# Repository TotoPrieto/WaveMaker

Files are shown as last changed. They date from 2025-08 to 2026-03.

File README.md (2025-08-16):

# 🌊 WaveMaker

**WaveMaker** is a wave generator developed at the **LEICI Laboratory** of the **Facultad de Ingenieria - UNLP**, designed to simulate wave motion inside a small water tank. It was created to test various wave amplitudes and speeds, with the final goal of supporting the study of waves energy harvesting systems placed inside the tank (a oscillating water column – not part of this project).

## 🛠️ Technical Description

The system uses a vertical linear actuator driven by a stepper motor, moving a wedge inside the tank to generate waves. One limit switch defines the zero position (home), while the second acts as a safety limit in case of unexpected movement or step miscounts.

### 🧩 Components

- Arduino UNO  
- CNC Shield V3 for Arduino  
- A4988 Stepper Motor Driver  
- NEMA17 Stepper Motor, 1.8º
- 24V 3A Power Supply  
- 2 Limit Switches  
- Power, Reset and speed mode Buttons
- Potentiometer

### 💻 Software

The firmware was developed using **PlatformIO**, programmed in **C++** with the **Arduino** library.

Included features:

- Homing routine using limit switches  
- Stepper control for vertical movement along Z-axis  
- Error handling and movement boundaries
- Selectable speed modes via button
- Amplitude control via analog potentiometer

## 🎚️ Speed Modes

The system includes **three selectable speed modes** using the dedicated speed selector button. Each mode modifies the way the stepper motor drives the vertical actuator, demonstrating different wave behaviors in the tank.

### Mode 1 – Variable Amplitude with Acceleration
- **Description:** The motor moves with acceleration and deceleration, and the amplitude of movement is adjustable using the analog potentiometer.
- **Implementation:** Uses `stepper.run()` from the `<AccelStepper.h>` library.
- **Purpose:** Demonstrates how changing the stroke amplitude directly affects the wave size, allowing for controlled testing of wave heights.

### Mode 2 – Constant Speed (No Acceleration)
- **Description:** The motor moves from one limit switch to the opposite one at a fixed speed, without acceleration or deceleration.
- **Implementation:** Uses `stepper.runSpeedToPosition()` from the `<AccelStepper.h>` library.
- **Purpose:** Simulates waves with a more "chaotic" surface, useful for observing the behavior inside the oscillating water column.

### Mode 3 – Accelerated Travel Between Limits
- **Description:** Similar to Mode 2, but movement between limit switches includes acceleration and deceleration.
- **Implementation:** Uses `stepper.run()` from the `<AccelStepper.h>` library.
- **Purpose:** Offers a different approach to crossing the entire stroke, still producing chaotic waves but with smoother motion transitions.

---

**Summary:**  
- Mode 1 focuses on **wave height control** (amplitude adjustment).  
- Modes 2 and 3 focus on **full-stroke chaotic wave generation** but differ in motor acceleration profiles.

## 📐 3D Modeling

The mechanical structure was designed using **AutoCAD** and **Blender**. Below are 3D rendered images of the model:

### Side View  


### Front View  


### Bottom View  


## ⚙️ Installation

1. Clone this repository locally.
2. Open the project using [PlatformIO](https://platformio.org/).
3. Connect the Arduino UNO via USB.
4. Compile and upload the firmware.

## 📁 Project Structure

```
WAVEGENERATOR/
├── .pio/
├── .vscode/
├── include/              # Header files
│   ├── Button.hpp
│   ├── Pins.hpp
│   └── StepperController.hpp
├── lib/ 
├── src/                  # Source code in C++
│   ├── Button.cpp
│   ├── main.cpp
│──  └── StepperController.cpp
├── 3D Models/            # Models Files
```

## ✒️ Authors

Project developed by **Tomas Prieto De Francia**, in colaboration with **Jeronimo Jose More** and **Facundo Mosquera**, and based on previous work by **Facundo Mosquera**, under the LEICI Laboratory at the **Universidad Nacional de La Plata (UNLP)**.

## 🪪 License

This project is licensed under the [MIT License](https://opensource.org/licenses/MIT).  
Feel free to use, modify, and share it for personal, academic, or commercial purposes.

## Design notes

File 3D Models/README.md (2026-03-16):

# 📐 WaveMaker - 3D Model Components

This repository contains 3D model files (`.stl`) designed for the mechanical parts of the **WaveMaker** system. These models were created to support the wave generation mechanism inside a small water tank.

## 🔩 Components Overview

### Slider

- Designed to be driven by a threaded rod via a nut that is inserted into the slider.
- Includes slots to mount linear roller bearings.
- Bearings can be secured using zip ties (cable ties).
- Improves stability and reduces friction during vertical movement.

### Main Body

- One side features a slot for a **ball bearing** to stabilize the threaded rod.
- The opposite side includes a mounting space for a **NEMA17 Stepper Motor (1.8º)**.
- Provides structural support for the entire movement mechanism.

### Wedge (Wave Generator)

- The wedge is a hollow structure used to generate waves inside the tank.
- Comes with a **removable top lid** that can be screwed in place.
- The hollow body allows for optional filling (e.g., sand, water, weights) to **increase mass and wave impact**.

### Control Button Enclosure

An additional 3D printable enclosure for the WaveMaker control buttons.

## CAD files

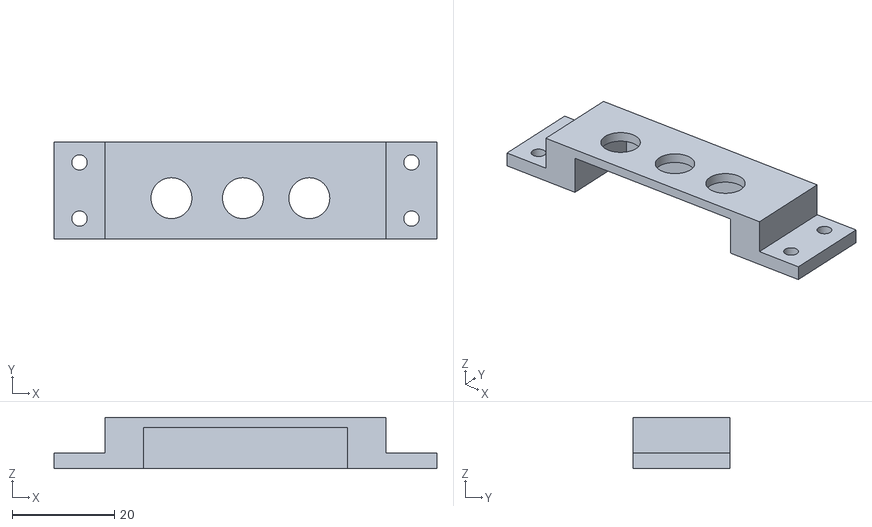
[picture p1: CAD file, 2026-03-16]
3D Models/Botonera.stl
75.0 x 19.0 x 10.0

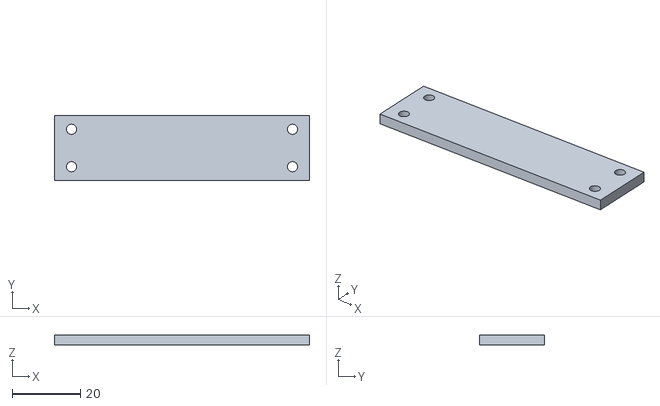
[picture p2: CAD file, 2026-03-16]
3D Models/SueloBotonera.stl
75.0 x 19.0 x 3.00

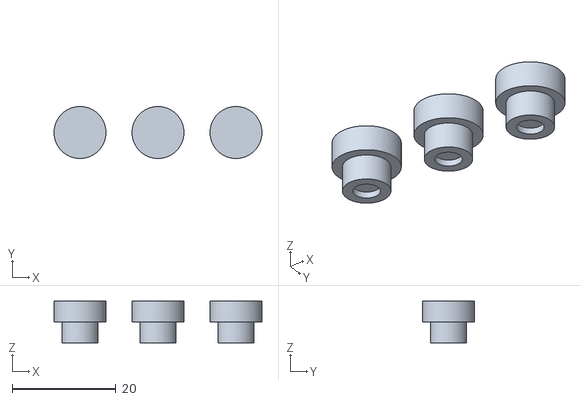
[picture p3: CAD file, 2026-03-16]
3D Models/Botones.stl
40.0 x 10.0 x 8.00

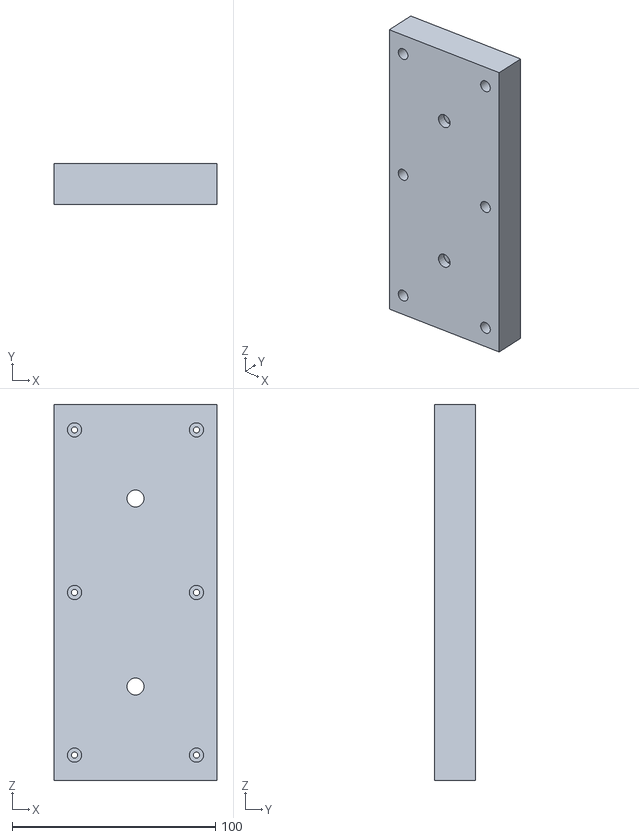
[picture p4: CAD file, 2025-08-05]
3D Models/Wedge-Cap.stl
80.0 x 20.0 x 185.0

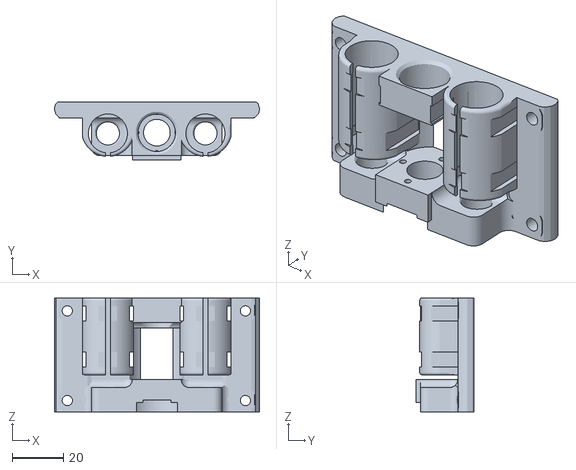
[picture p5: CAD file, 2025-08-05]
3D Models/Slider.stl
80.0 x 22.7 x 44.5

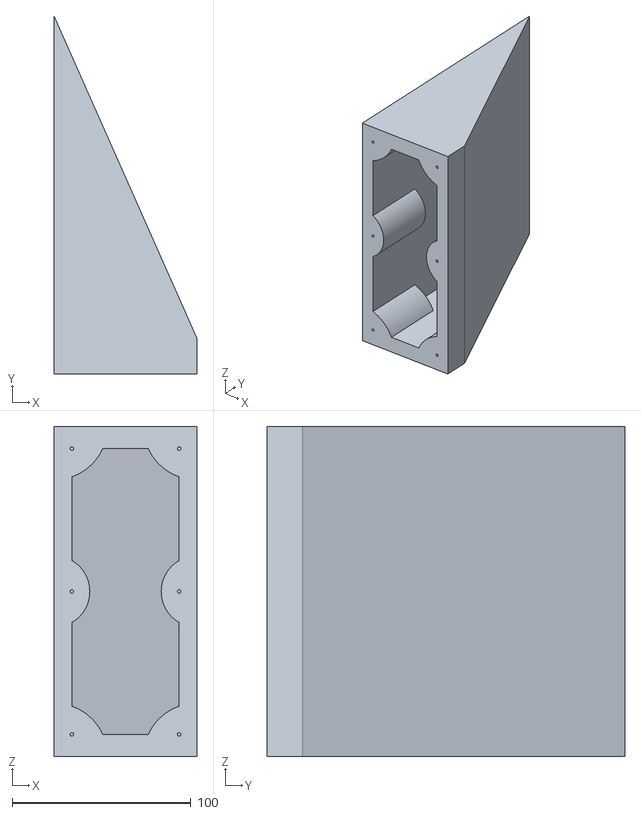
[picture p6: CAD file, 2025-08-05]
3D Models/Wedge.stl
80.0 x 200.4 x 185.0

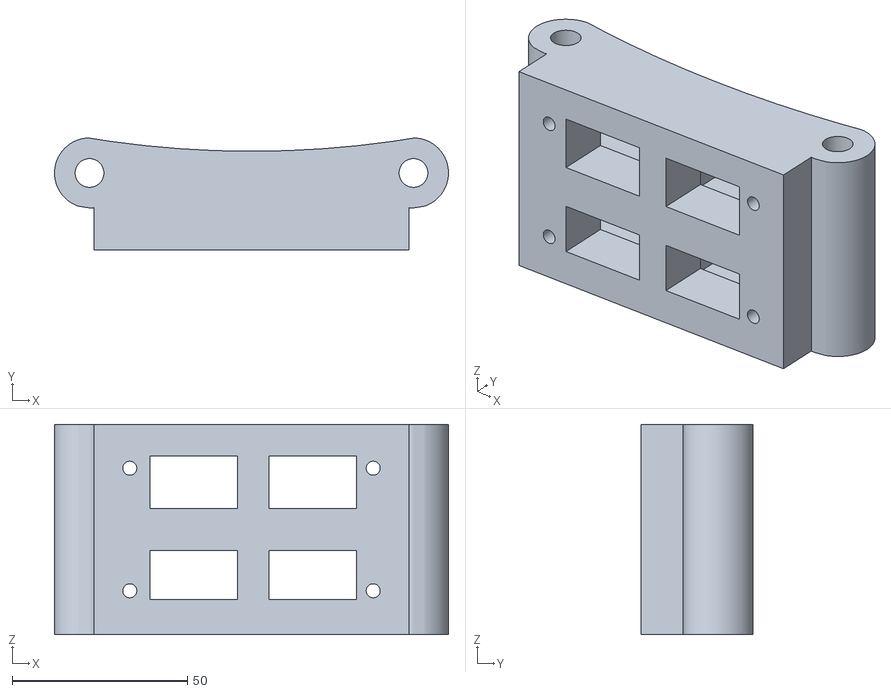
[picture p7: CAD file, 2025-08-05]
3D Models/Arm.stl
112.5 x 32.0 x 60.0

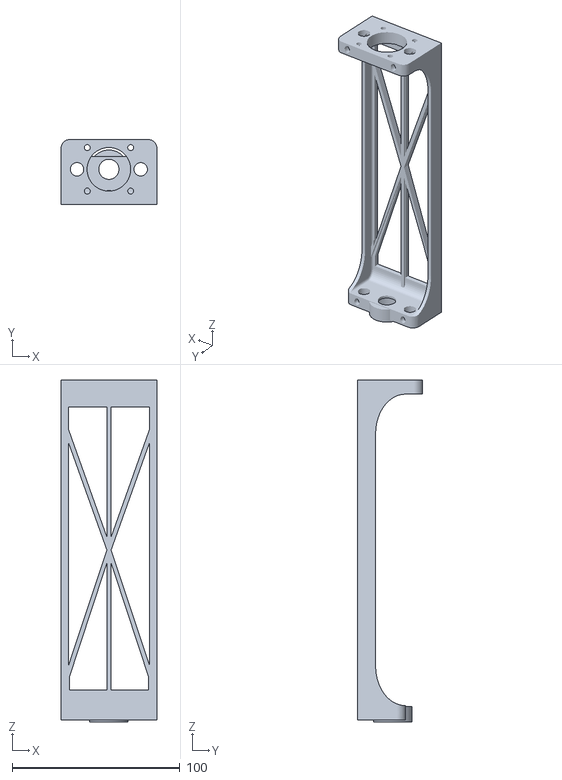
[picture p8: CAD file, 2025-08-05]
3D Models/Body.stl
57.2 x 38.7 x 204.0

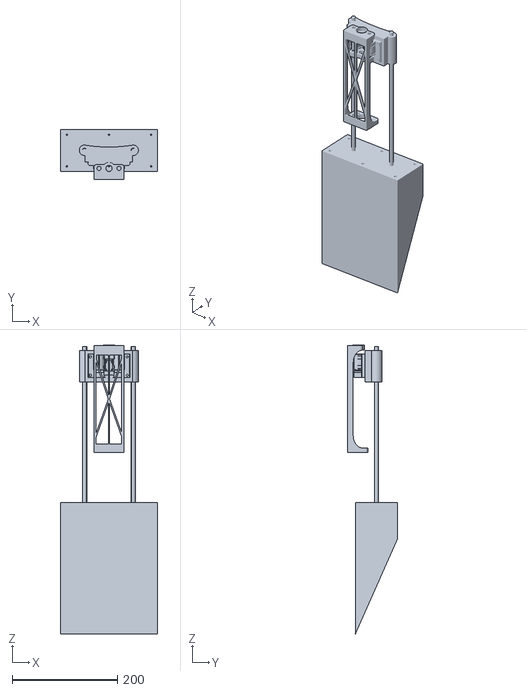
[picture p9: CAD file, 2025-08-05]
3D Models/PiecesTogether.stl
185.0 x 94.8 x 549.3

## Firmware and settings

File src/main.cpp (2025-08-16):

#include <Arduino.h>
#include "StepperController.hpp"
#include "Button.hpp"
#include "Pins.hpp"

//Initial total steps
int steps_Tot = MAX_STEPS;
//State of the system: ON or OFF
volatile bool systemOn = false;
//Define the stepper controller with the pins and total steps
StepperController controller(STEP_PIN, DIR_PIN, ENABLE_PIN);

//My three buttons and both limit switches are active low

//Reset button. Does init action
Button resetButton(RESET_BUTTON_PIN, true, []() {
controller.init(steps_Tot);
});

//Power button to toggle the system state and enable/disable the motor
Button powerButton(POWER_BUTTON_PIN, true, []() {
    systemOn = !systemOn;
    if (systemOn) {
        controller.enable(steps_Tot);
    } else {
        controller.emergencyStop();
    }
});

//Speed mode button. Changes how the motor steps
Button changeSpeedButton(SPEED_MODE_PIN, true, []() {
    controller.changeSpeedMode();
});

//Minimum limit switch
Button minSwitch(LIMIT_MIN_PIN,true, []() {
    controller.handleMinTrigger(steps_Tot);
});

//Maximum limit switch
Button maxSwitch(LIMIT_MAX_PIN,true, []() {
    controller.handleMaxTrigger();
});


//Read the potentiometer and map its value to my range of steps
void checkPotentiometer() {
  // Read the potentiometer value
  int potValue = analogRead(POTENTIOMETER_PIN);
  // Map the potentiometer value to my range
  steps_Tot = map(potValue, 0, 1023, MAX_STEPS, MIN_STEPS);
}

//Initial setup
void setup() {
    //When the system starts, it is off
    systemOn = false;

    //Check the initial position of the potentiometer
    checkPotentiometer();

    //Initialize the stepper controller
    controller.init(steps_Tot);
    
    // Configure power button pin for interrupt
    pinMode(POWER_BUTTON_PIN, INPUT_PULLUP);
}

// Checks values of limit switches, buttons, potentiometer and updates the stepper controller
void loop() {
    powerButton.update();
    resetButton.update();
    checkPotentiometer();
    changeSpeedButton.update();
    //Just works when the system is ON
    if (systemOn) {
        minSwitch.update();
        maxSwitch.update();
        controller.update(steps_Tot);
    }
}

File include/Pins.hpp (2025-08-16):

//Motor pins
#define STEP_PIN       4
#define DIR_PIN        7
#define ENABLE_PIN     8
//Limit switches pins
#define LIMIT_MIN_PIN  9
#define LIMIT_MAX_PIN  11
//Button pins
#define POWER_BUTTON_PIN  10
#define RESET_BUTTON_PIN  14
#define SPEED_MODE_PIN   15
//Potentiometer pin and range
#define POTENTIOMETER_PIN  16
#define MAX_STEPS    1700 // Maximum steps for my stepper motor
#define MIN_STEPS    700   // Minimum steps for my stepper motor

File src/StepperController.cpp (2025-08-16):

#include "StepperController.hpp"
#include "Pins.hpp"
#include <Arduino.h>

// Constructor
StepperController::StepperController(uint8_t stepPin, uint8_t dirPin, uint8_t enablePin) 
: stepper(AccelStepper::DRIVER, stepPin, dirPin),
  enablePin(enablePin),
  movingToMin(true) {}

// Initialize the stepper motor
void StepperController::init(int steps_Tot) {
    pinMode(enablePin, OUTPUT);
    digitalWrite(enablePin, LOW);
    //Values for step with acceleration
    stepper.setMaxSpeed(5000);
    stepper.setAcceleration(3000);

    homingSequence();
    //Values for step with constant speed
    stepper.setSpeed(1000);

    currentSpeedMode = 0;
}

// Homing sequence to find the minimum position and declare the zero
void StepperController::homingSequence() {

    // Move to the minimum position until the limit switch is pressed
    stepper.setCurrentPosition(0);
    stepper.moveTo(-2000);
    while (digitalRead(LIMIT_MIN_PIN) == HIGH) {
        stepper.run();
    }
    stepper.stop();
    stepper.setCurrentPosition(0);
    //Change direction to positive
    movingToMin = false;
    stepper.moveTo(2000);
    
}


// In case minimum limit switch is pressed then stop, declare zero position and set destination
void StepperController::handleMinTrigger(int steps_Tot) {
    // Set the destination based on the current speed mode
    switch(currentSpeedMode){
        case 0:
            //The destination is defined with the potenciometer
            destinationMin = steps_Tot;
            break;
        case 1: 
            //Much higher than MAX_STEPS in order to ensure it reaches the limit
            destinationMin = 2200;
            break;
        case 2:
            //Much higher than MAX_STEPS in order to ensure it reaches the limit
            destinationMin = 2200;
            break;
    }

    //"IF sentence" to avoid problems
    if (stepper.distanceToGo() != 0) {
        stepper.stop();
        stepper.setCurrentPosition(0);
        stepper.moveTo(destinationMin);
        movingToMin = false;
    }
}

// In case the maximum limit switch is pressed then stop, declare zero position(helps to stop suddenly) and set destination
void StepperController::handleMaxTrigger() {
    //"IF sentence" to avoid problems
    if (stepper.distanceToGo() != 0) {
        stepper.stop();
        stepper.setCurrentPosition(0);
        //Much lower than zero in order to ensure it reaches the limit
        stepper.moveTo(-2200);
        movingToMin = true;
    }
}


//Update the stepper position when stepper completes its movement
void StepperController::update(int steps_Tot) {
    switch(currentSpeedMode) {
 
        case 0:
        //This mode changes the speed depending the destination. The range doesn't touch de limit switch
            //If moving to -Z, moves with acceleration
            if (movingToMin) {
                // Move towards the minimum position with acceleration
                stepper.run();
                // If the stepper has reached the destination, change direction manually
                if (stepper.distanceToGo() == 0) {
                    stepper.stop();
                    movingToMin = false;
                    // Sets the next position to go that doesn't touch the limit switch
                    stepper.moveTo(steps_Tot);
                    // Sets values for the other direction
                    stepper.setSpeed(1000);
                }
            }else{
                //If moving to +Z, moves with constant speed (no acceleration)
                stepper.runSpeedToPosition();
                if (stepper.distanceToGo() == 0) {
                    stepper.stop();
                    movingToMin = true;
                    // Sets the next position to go that doesn't touch the limit switch
                    stepper.moveTo(100);
                    // Sets values for the other direction
                    stepper.setMaxSpeed(9000);
                    stepper.setAcceleration(3000);
            }
            break;

        case 1:
        //This mode goes from limit switch to limit switch at constant speed
            stepper.setSpeed(1000);
            stepper.runSpeedToPosition();
            break;

        case 2:
        //This mode goes from limit switch to limit switch with acceleration/deceleration
            stepper.run();
            break;
        }
    }
}

// Enable the stepper motor
void StepperController::enable(int steps_Tot) {

    // Checks the actual destination depending the mode to avoid changing it unexpectedly
    switch(currentSpeedMode){
        case 0:
            destinationMin = steps_Tot;
            break;
        case 1: 
            destinationMin = 2200;
            break;
        case 2:
            destinationMin = 2200;
            break;
    }
    //Enable the motor
    digitalWrite(enablePin, LOW);
    
    //Set the previous movement without changing direction when the motor is stopped
    if (stepper.distanceToGo() == 0) {
        stepper.moveTo(movingToMin ? 0 : destinationMin);
    }
}

// Disable the stepper motor
void StepperController::emergencyStop() {
    // Stop any current movement immediately
    stepper.setSpeed(0);
    stepper.stop();
    
    // Force immediate stop
    stepper.setCurrentPosition(stepper.currentPosition());
    
    // Disable the motor
    digitalWrite(enablePin, HIGH); 
}

// Change the speed mode and perform homing if necessary to avoid problems
void StepperController::changeSpeedMode() {
    currentSpeedMode = (currentSpeedMode + 1) % 3;
    stepper.stop();
        //Do homing in case sistem is ON
    if (digitalRead(enablePin) == LOW) {
        homingSequence();
    }
    //Set all values of speed
    stepper.setSpeed(1000);
    stepper.setMaxSpeed(3000);
    stepper.setAcceleration(2000);
}

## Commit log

2025-08-05 Modelos ya impresos
    [Arm.stl, Body.stl, PiecesTogether.stl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]
2025-08-05 Pin Y ya no funciona mal. Boton reset actualizado a activeHigh
    [Pins.hpp, main.cpp]
2025-08-05 Agrego potenciometro para amplitud. Defino velocidades permitidas
2025-08-06 Cambio manera de detener y arrancar el motor
2025-08-06 Mejoro manera de operar de boton reset y power
    [main.cpp]
2025-08-07 Cambio el punto "cero". Ahora es en Z-
2025-08-07 Ahora arranca con los pasos correctos desde el init()
    [StepperController.cpp, main.cpp]
2025-08-12 Version bruta pero que funciona
2026-03-16 Agrego botonera
    [Botonera.stl, Botones.stl, SueloBotonera.stl]
